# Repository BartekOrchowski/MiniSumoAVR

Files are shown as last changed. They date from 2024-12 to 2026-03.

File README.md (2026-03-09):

## MiniSumo Robot – ATmega328P 

This project is a MiniSumo robot developed during a workshop organized by the KoNaR student scientific association. It is based on the ATmega328P microcontroller and represents my first hands-on experience with designing, assembling, and programming a robot from scratch.

## Overview

The goal of the project was to create an autonomous MiniSumo robot that could:
- Detect and engage with an opponent using distance sensors
- Stay within the ring using line sensors
- Control DC motors for movement via an H-bridge

## Working Features

Despite the project being incomplete, several features were successfully implemented:
- ✅ **DC motor control** using an H-bridge
- ✅ **Distance measurement** from four VL53L0X sensors (basic functionality working)
- ✅ **ADC** for line sensor

## Issues and Challenges

Several hardware issues:
- ❌ Incorrect electrical connections
- ❌ Improper wiring of XSHUT pins for the VL53L0X distance sensors

Due to these problems, the robot was not fully operational, and the project was paused before final testing and competition.

## Future Plans

Although the current version of the robot is unfinished, I may return to this project in the future to redesign the PCB, correct the hardware issues, and complete the software stack.

---

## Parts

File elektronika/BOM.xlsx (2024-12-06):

Reference | Value
C1, C2, C3, C4, C13, C16 | 100n
C5, C6, C7, C8, C11, C12 | 10u
C14, C15 | 22p
D1, D2 | LED
J1 | SPI
J2 | Conn_01x02_Pin
J3 | Conn_01x03_Pin
J4, J5, J6, J7 | Conn_01x06_Pin
M1, M2 | ~
Q2 | AO3401A
R1 | 200R
R2, R3, R7 | 10k
R4, R6, R8, R9, R11, R13 | 1k
R5, R10, R12, R14 | 2k
U1 | ATmega328P-A
U2, U3 | TB6612FNG
U4, U5 | ITR8307
U7 | AMS1117-5.0
Y1 | Crystal

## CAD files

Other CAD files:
mechanika/OldVersions/plytka.0001.ipt
mechanika/czujnik.ipt
mechanika/plytka.ipt
mechanika/silnik.ipt

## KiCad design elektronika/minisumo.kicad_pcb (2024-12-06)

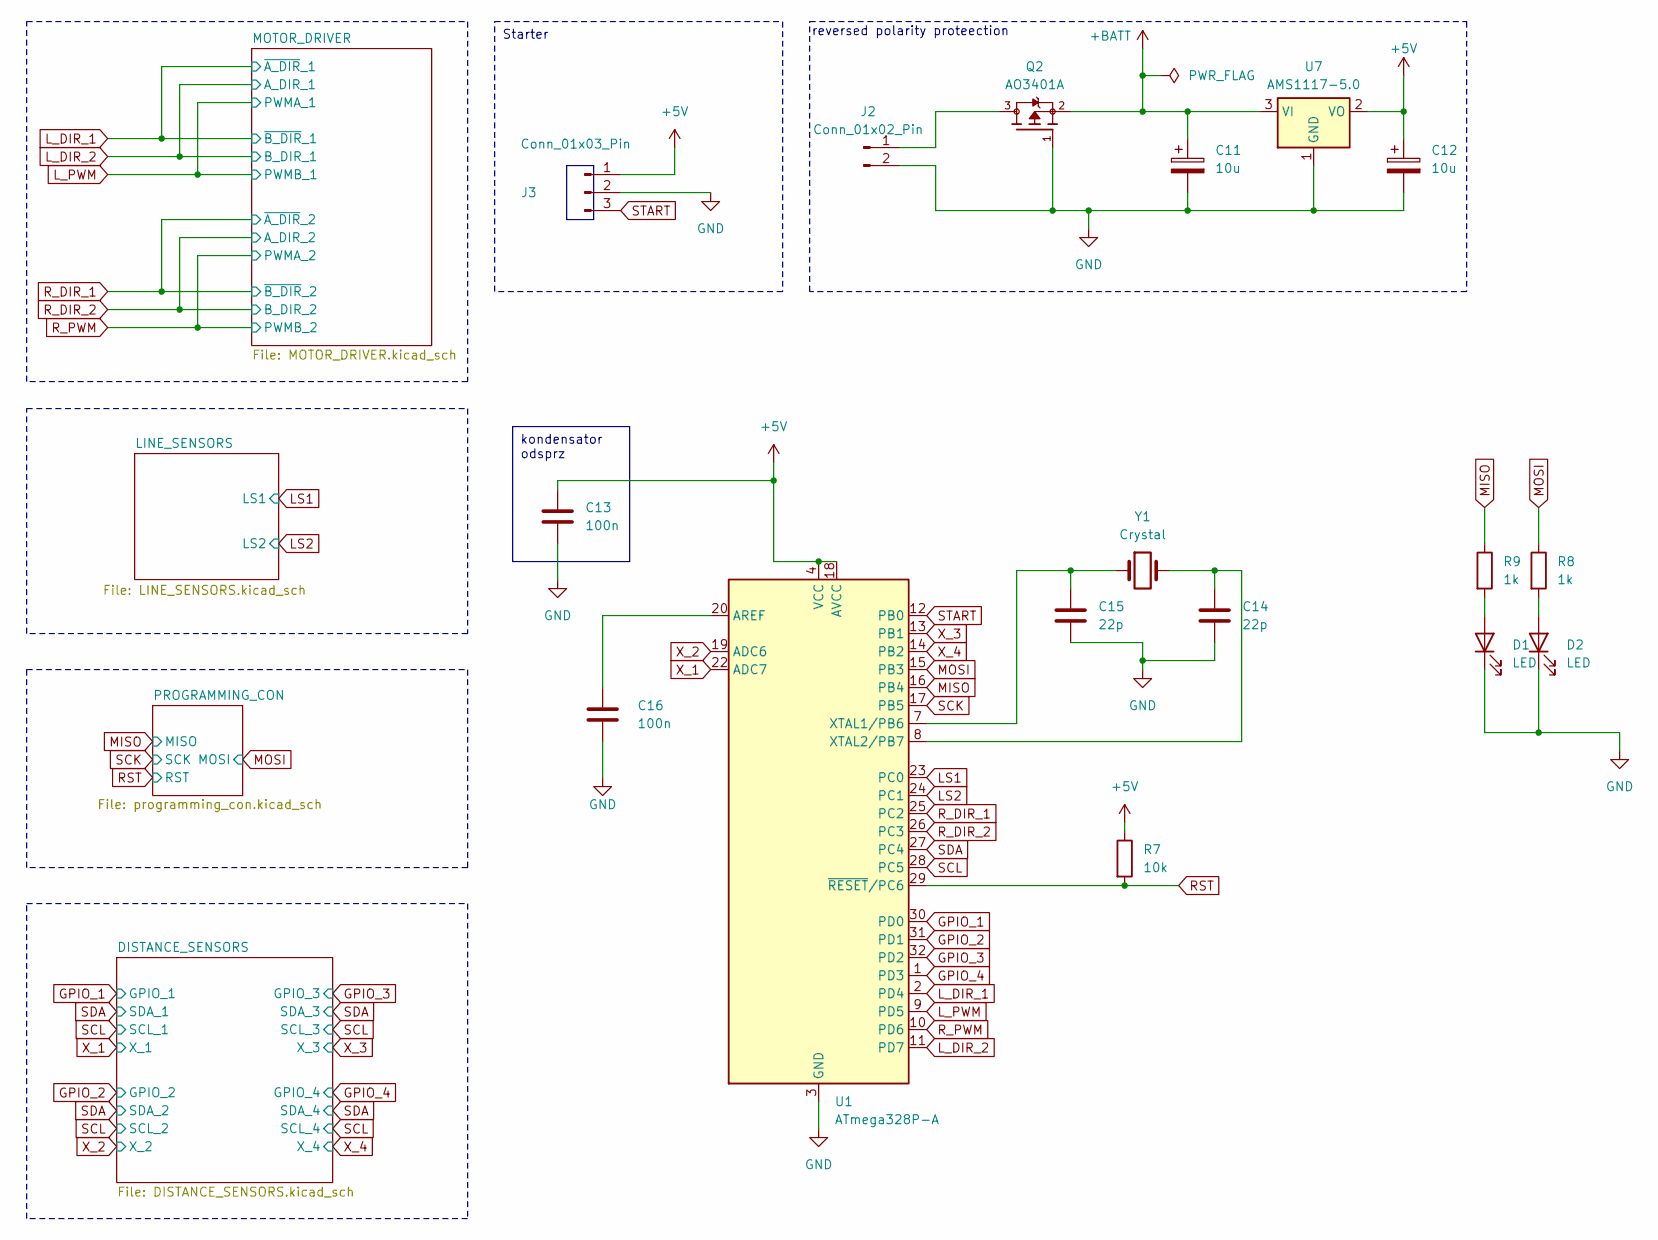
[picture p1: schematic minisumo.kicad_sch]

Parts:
C11, C12: 10u; CP_EIA-3528-21_Kemet-B_Pad1.50x2.35mm_HandSolder
C13, C16: 100n; LED_0805_2012Metric_Pad1.15x1.40mm_HandSolder
C14, C15: 22p; LED_0805_2012Metric_Pad1.15x1.40mm_HandSolder
D1, D2: LED; LED_0805_2012Metric_Pad1.15x1.40mm_HandSolder
J2: Conn_01x02_Pin; PinHeader_1x02_P2.54mm_Vertical
J3: Conn_01x03_Pin; PinHeader_1x03_P2.54mm_Vertical
Q2: AO3401A; SOT23-3; DigiKey_Part_Number 785-1001-2-ND
R7: 10k; R_0805_2012Metric_Pad1.20x1.40mm_HandSolder
R8, R9: 1k; R_0805_2012Metric_Pad1.20x1.40mm_HandSolder
U1: ATmega328P-A; TQFP-32_7x7mm_P0.8mm
U7: AMS1117-5.0; SOT-223-3_TabPin2
Y1: Crystal; Crystal_HC18-U_Vertical

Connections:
+5V: C12.1, C13.1, J3.1, R7.1, U1.4 (VCC), U1.6 (VCC), U1.18 (AVCC), U7.2 (VO); also elsewhere on the board
+BATT: C11.1, Q2.2, U7.3 (VI); also elsewhere on the board
GND: C11.2, C12.2, C13.2, C14.2, C15.2, C16.2, D1.1 (K), D2.1 (K), J2.2, J3.2, Q2.1, U1.3 (GND), U1.5 (GND), U1.21 (GND), U7.1 (GND); also elsewhere on the board
GPIO_1: U1.30 (PD0); also elsewhere on the board
GPIO_2: U1.31 (PD1); also elsewhere on the board
GPIO_3: U1.32 (PD2); also elsewhere on the board
GPIO_4: U1.1 (PD3); also elsewhere on the board
LS1: U1.23 (PC0); also elsewhere on the board
LS2: U1.24 (PC1); also elsewhere on the board
L_DIR_1: U1.2 (PD4); also elsewhere on the board
L_DIR_2: U1.11 (PD7); also elsewhere on the board
L_PWM: U1.9 (PD5); also elsewhere on the board
MISO: R9.1, U1.16 (PB4); also elsewhere on the board
MOSI: R8.1, U1.15 (PB3); also elsewhere on the board
unnamed: D1.2 (A), R9.2
unnamed: D2.2 (A), R8.2
unnamed: J2.1, Q2.3
unnamed: C16.1, U1.20 (AREF)
unnamed: C15.1, U1.7 (XTAL1/PB6), Y1.1
unnamed: C14.1, U1.8 (XTAL2/PB7), Y1.2
RST: R7.2, U1.29 (~RESET/PC6); also elsewhere on the board
R_DIR_1: U1.25 (PC2); also elsewhere on the board
R_DIR_2: U1.26 (PC3); also elsewhere on the board
R_PWM: U1.10 (PD6); also elsewhere on the board
SCK: U1.17 (PB5); also elsewhere on the board
SCL: U1.28 (PC5); also elsewhere on the board
SDA: U1.27 (PC4); also elsewhere on the board
START: J3.3, U1.12 (PB0)
X_1: U1.22 (ADC7); also elsewhere on the board
X_2: U1.19 (ADC6); also elsewhere on the board
X_3: U1.13 (PB1); also elsewhere on the board
X_4: U1.14 (PB2); also elsewhere on the board

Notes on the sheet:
kondensator odsprz
Starter
reversed polarity proteection

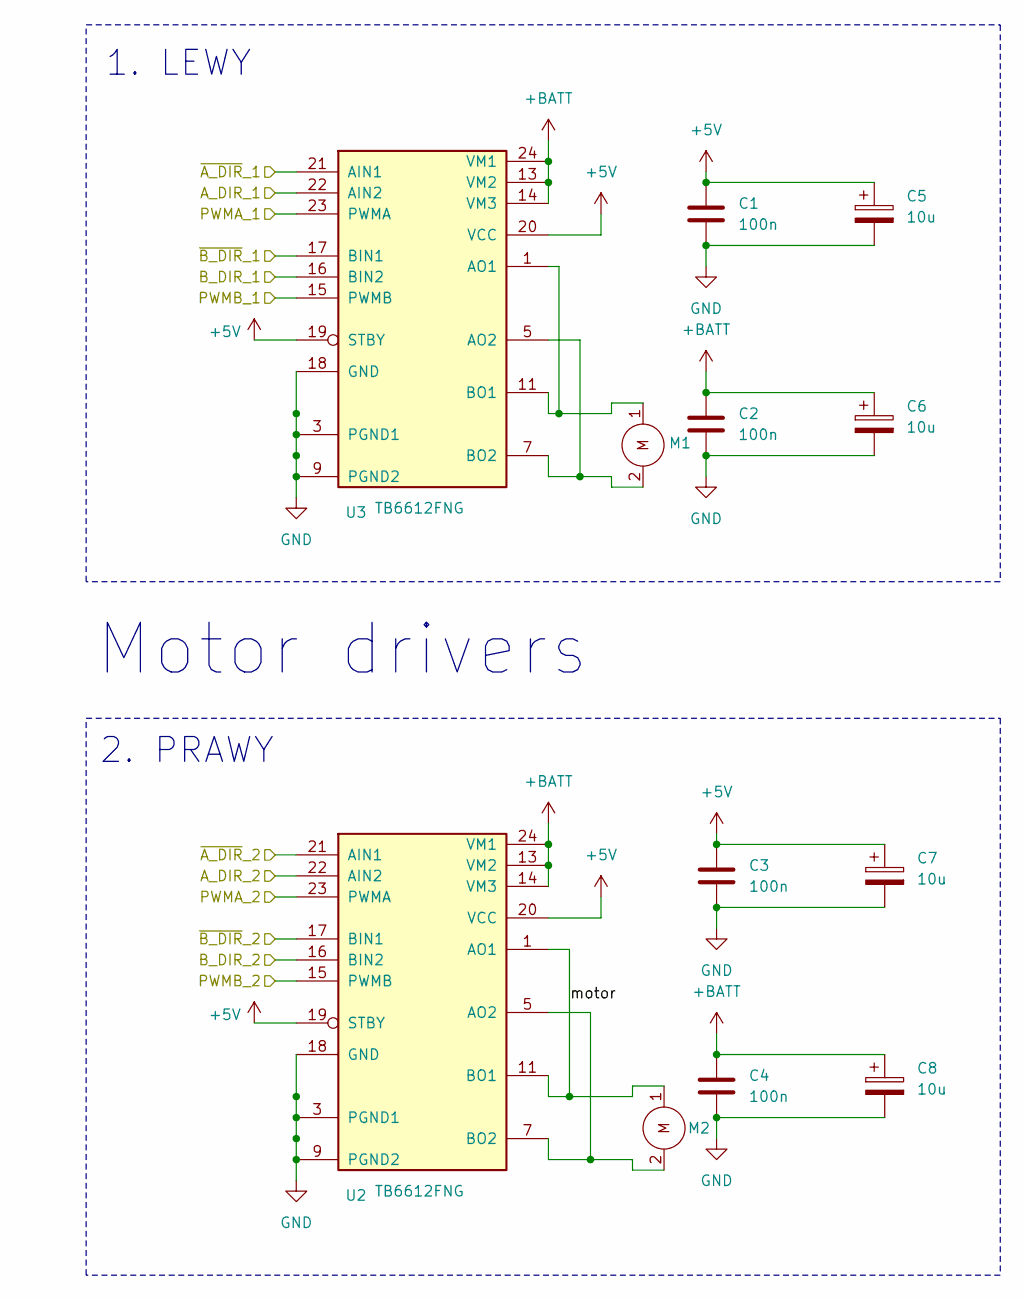
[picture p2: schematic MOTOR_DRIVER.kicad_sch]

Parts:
C1, C2, C3, C4: 100n; LED_0805_2012Metric_Pad1.15x1.40mm_HandSolder
C5, C6, C7, C8: 10u; CP_EIA-3528-21_Kemet-B_Pad1.50x2.35mm_HandSolder
M1, M2: Motor
U2, U3: TB6612FNG; SSOP-24_5.3x8.2mm_P0.65mm

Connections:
+5V: C1.1, C3.1, C5.1, C7.1, U2.19 (STBY), U2.20 (VCC), U3.19 (STBY), U3.20 (VCC); also elsewhere on the board
+BATT: C2.1, C4.1, C6.1, C8.1, U2.13 (VM2), U2.14 (VM3), U2.24 (VM1), U3.13 (VM2), U3.14 (VM3), U3.24 (VM1); also elsewhere on the board
/MOTOR_DRIVER/motor: M2.1, U2.1 (AO1), U2.2 (AO1), U2.11 (BO1), U2.12 (BO1)
GND: C1.2, C2.2, C3.2, C4.2, C5.2, C6.2, C7.2, C8.2, U2.3 (PGND1), U2.4 (PGND1), U2.9 (PGND2), U2.10 (PGND2), U2.18 (GND), U3.3 (PGND1), U3.4 (PGND1), U3.9 (PGND2), U3.10 (PGND2), U3.18 (GND); also elsewhere on the board
L_DIR_1: U3.17 (BIN1), U3.21 (AIN1); also elsewhere on the board
L_DIR_2: U3.16 (BIN2), U3.22 (AIN2); also elsewhere on the board
L_PWM: U3.15 (PWMB), U3.23 (PWMA); also elsewhere on the board
unnamed: M1.1, U3.1 (AO1), U3.2 (AO1), U3.11 (BO1), U3.12 (BO1)
unnamed: M1.2, U3.5 (AO2), U3.6 (AO2), U3.7 (BO2), U3.8 (BO2)
unnamed: M2.2, U2.5 (AO2), U2.6 (AO2), U2.7 (BO2), U2.8 (BO2)
R_DIR_1: U2.17 (BIN1), U2.21 (AIN1); also elsewhere on the board
R_DIR_2: U2.16 (BIN2), U2.22 (AIN2); also elsewhere on the board
R_PWM: U2.15 (PWMB), U2.23 (PWMA); also elsewhere on the board

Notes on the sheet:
1. LEWY
2. PRAWY
Motor drivers

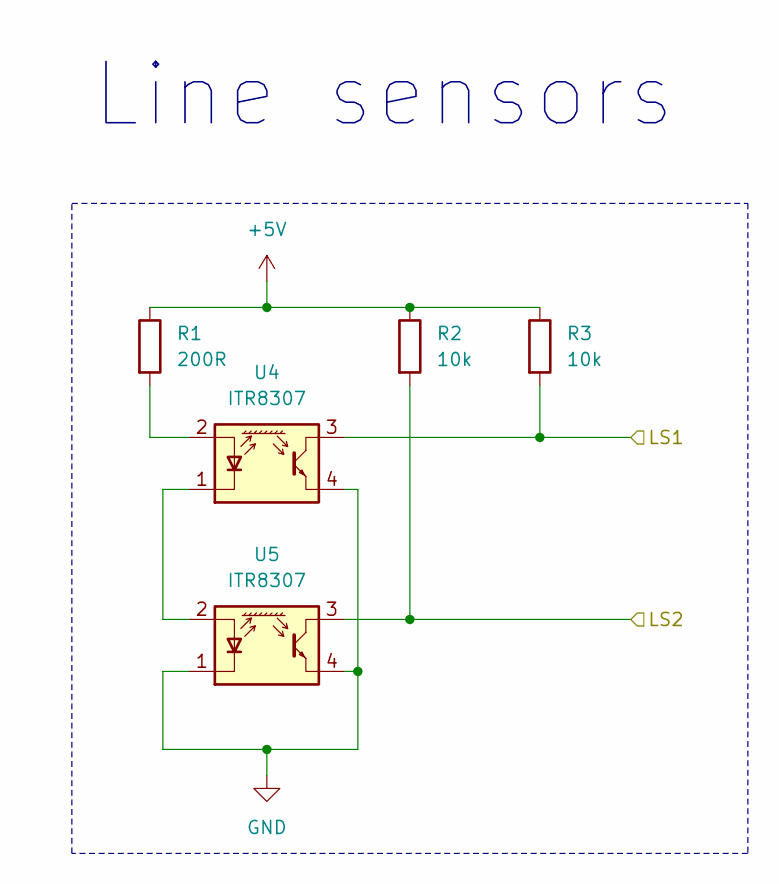
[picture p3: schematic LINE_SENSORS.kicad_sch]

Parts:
R1: 200R; R_0805_2012Metric_Pad1.20x1.40mm_HandSolder
R2, R3: 10k; R_0805_2012Metric_Pad1.20x1.40mm_HandSolder
U4, U5: ITR8307; Everlight_ITR1201SR10AR

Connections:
+5V: R1.1, R2.1, R3.1; also elsewhere on the board
GND: U4.4 (E), U5.1 (K), U5.4 (E); also elsewhere on the board
LS1: R3.2, U4.3 (C); also elsewhere on the board
LS2: R2.2, U5.3 (C); also elsewhere on the board
unnamed: R1.2, U4.2 (A)
unnamed: U4.1 (K), U5.2 (A)

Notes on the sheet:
Line sensors

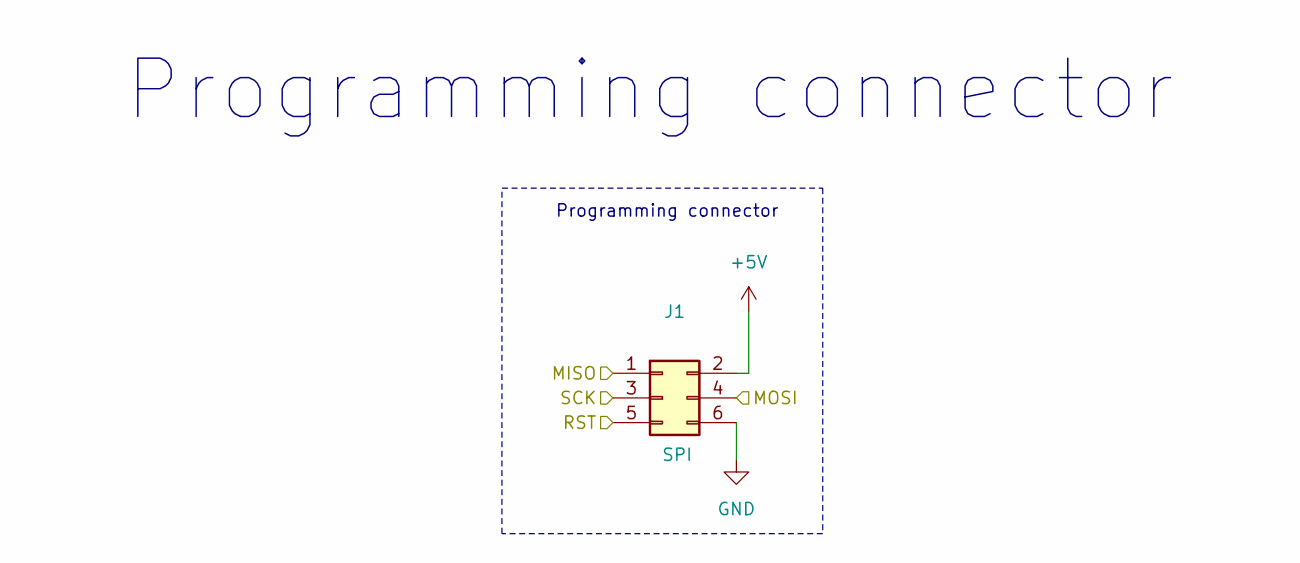
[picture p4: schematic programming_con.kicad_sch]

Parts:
J1: SPI; PinHeader_2x03_P2.54mm_Vertical

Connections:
+5V: J1.2; also elsewhere on the board
GND: J1.6; also elsewhere on the board
MISO: J1.1; also elsewhere on the board
MOSI: J1.4; also elsewhere on the board
RST: J1.5; also elsewhere on the board
SCK: J1.3; also elsewhere on the board

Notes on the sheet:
Programming connector

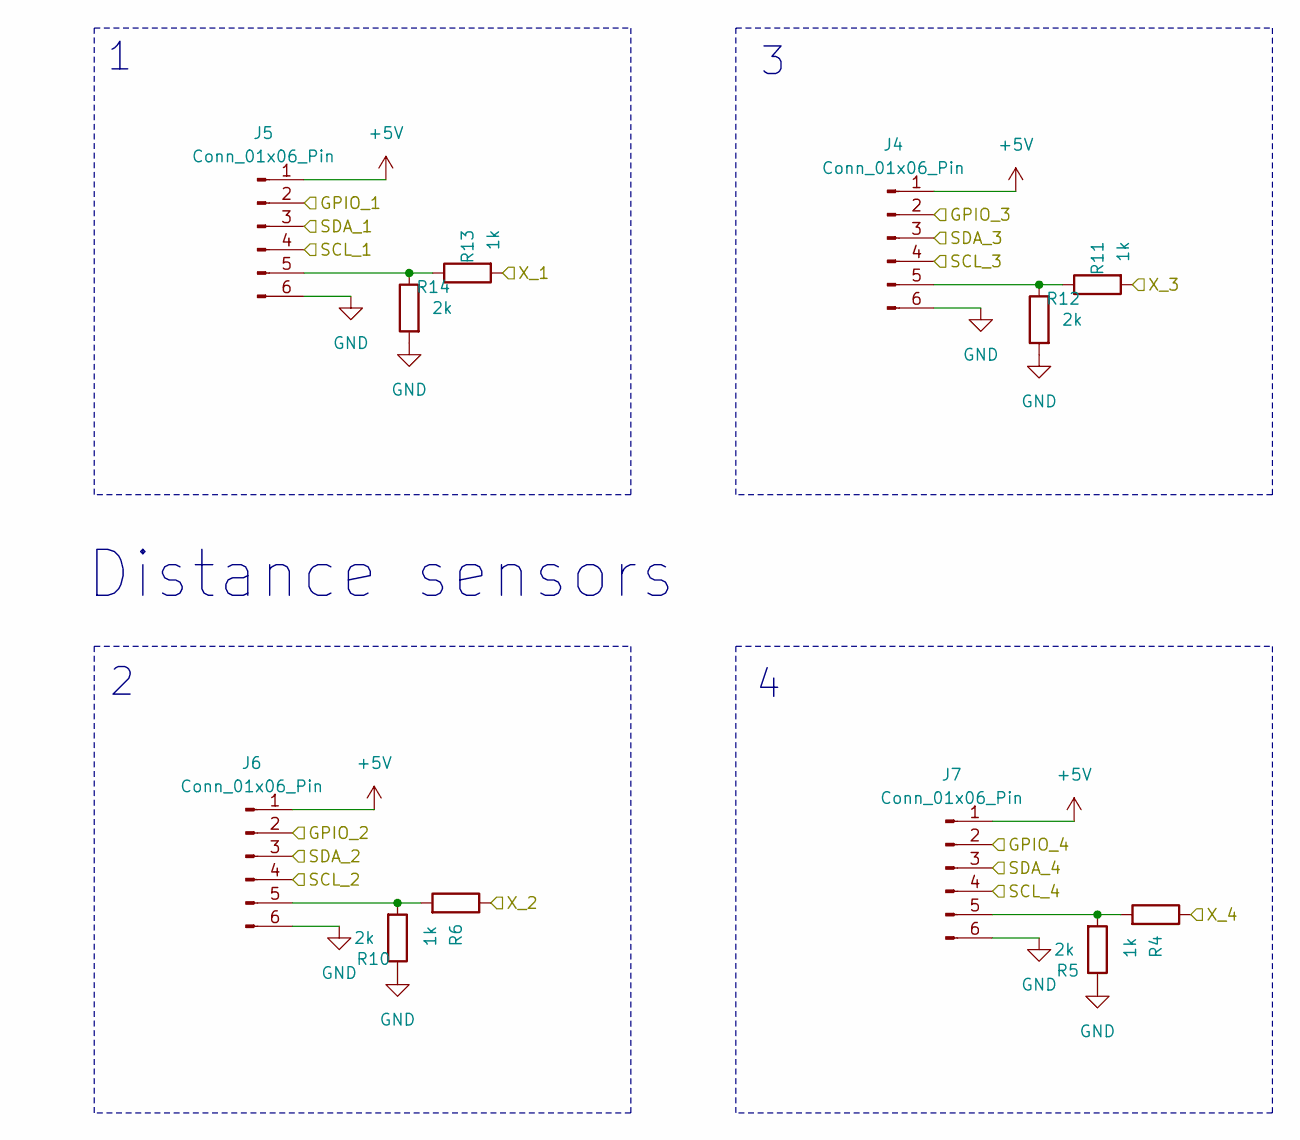
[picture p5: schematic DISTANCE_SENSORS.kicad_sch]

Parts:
J4, J5, J6, J7: Conn_01x06_Pin; PinHeader_1x06_P2.54mm_Vertical
R4, R6, R11, R13: 1k; R_0805_2012Metric_Pad1.20x1.40mm_HandSolder
R5, R10, R12, R14: 2k; R_0805_2012Metric_Pad1.20x1.40mm_HandSolder

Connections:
+5V: J4.1, J5.1, J6.1, J7.1; also elsewhere on the board
GND: J4.6, J5.6, J6.6, J7.6, R5.1, R10.1, R12.2, R14.2; also elsewhere on the board
GPIO_1: J5.2; also elsewhere on the board
GPIO_2: J6.2; also elsewhere on the board
GPIO_3: J4.2; also elsewhere on the board
GPIO_4: J7.2; also elsewhere on the board
unnamed: J4.5, R11.1, R12.1
unnamed: J5.5, R13.1, R14.1
unnamed: J6.5, R6.2, R10.2
unnamed: J7.5, R4.2, R5.2
SCL: J4.4, J5.4, J6.4, J7.4; also elsewhere on the board
SDA: J4.3, J5.3, J6.3, J7.3; also elsewhere on the board
X_1: R13.2; also elsewhere on the board
X_2: R6.1; also elsewhere on the board
X_3: R11.2; also elsewhere on the board
X_4: R4.1; also elsewhere on the board

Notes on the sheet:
Distance sensors

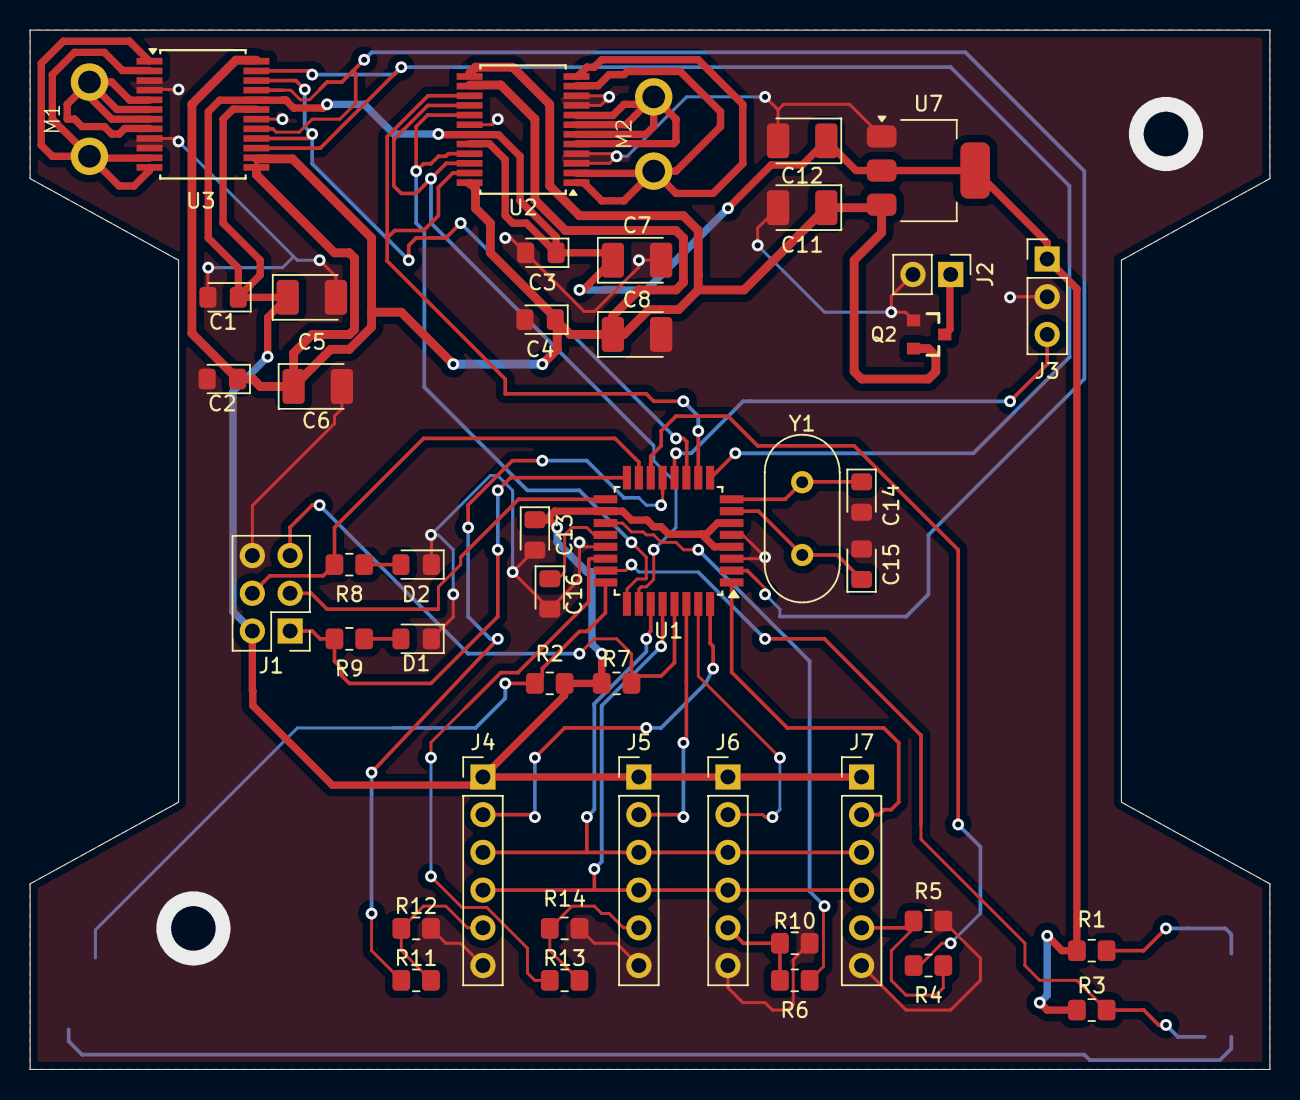
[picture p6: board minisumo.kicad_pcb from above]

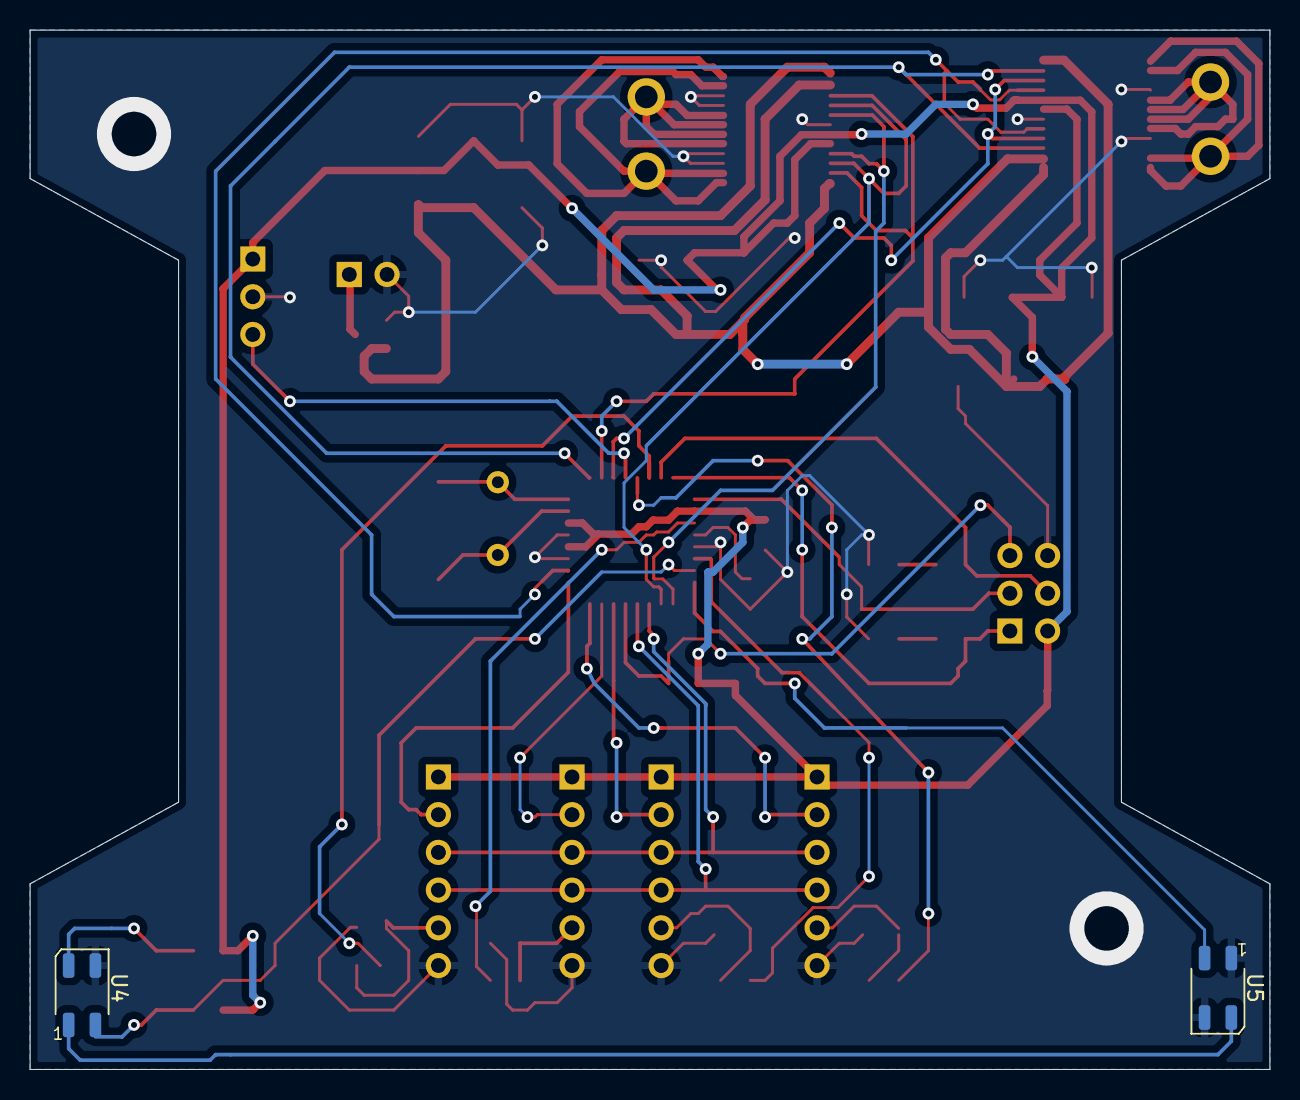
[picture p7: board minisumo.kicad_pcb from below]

Board: 2 copper layers, 83.5 x 70.0 mm, 47 parts (2 on the bottom side), 42 nets.

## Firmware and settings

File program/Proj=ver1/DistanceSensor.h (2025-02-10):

#pragma once

#include <stdint.h>
#include <avr/io.h>
#include <avr/delay.h>				

#include "vl53l0x.h"
#include "I2C.h"

void Timer1_Init(void); 

//Distance sensors
// XSHUT pins (dla czujników VL53L0X)
#define XSHUT_SENSOR1 PD0
#define XSHUT_SENSOR2 PD1				///////////////////////////////////connect x1 and x2 using jumper cables to pd0 and pd1
#define XSHUT_SENSOR3 PB1
#define XSHUT_SENSOR4 PB2

// I2C Addresses for sensors
#define SENSOR1_ADDR 0x30
#define SENSOR2_ADDR 0x31
#define SENSOR3_ADDR 0x32
#define SENSOR4_ADDR 0x33

void Xshut_Init(void);
void Xshut_Disable(uint8_t pin);
void Xshut_Enable(uint8_t pin);
void DistanceSensor_Init(void);
void DistanceSensor_SetAddr(uint8_t new_address);
uint16_t DistanceSensor_Read(uint8_t sensor_address);

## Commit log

2025-02-10 Motor Drivers
2025-02-28 PWM fight
2025-02-28 PWM fight2
2025-03-14 motor+line sensor
2025-03-18 Mechanika + dystans
    [czujnik.ipt, plytka.0001.ipt, plytka.ipt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]
2025-06-10 Line sensors ADC
